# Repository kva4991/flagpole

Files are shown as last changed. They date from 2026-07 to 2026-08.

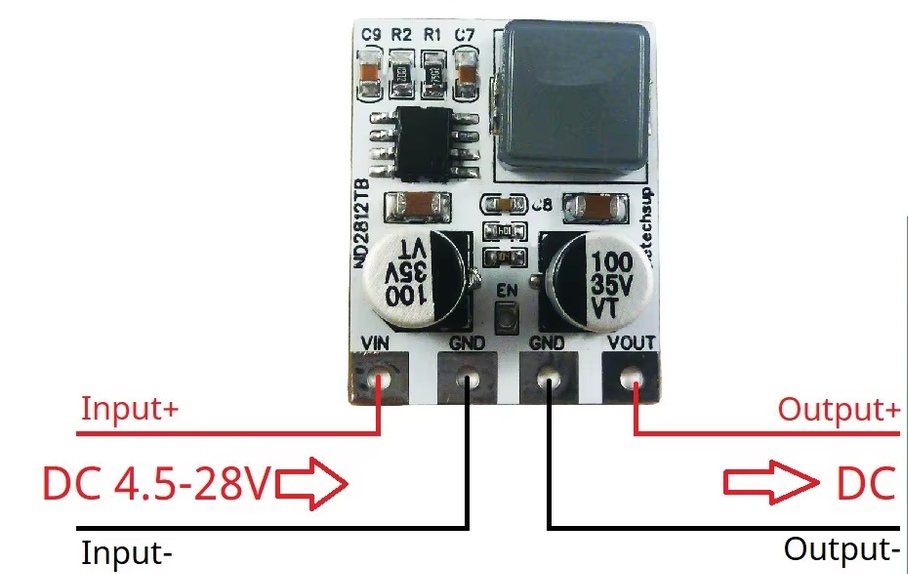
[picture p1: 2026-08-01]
catalog/images/eletechsup_buck_5v_wiring_1005005870795744.png

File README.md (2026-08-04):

# Super_pommels_and_flag rotating flagpole finial v0.7.6

Super_pommels_and_flag is an experimental rotating flagpole-finial project combining printable PETG/TPU mechanics, a 12 V illuminated fish flag, ESP32-C3 firmware, BLE control, a local Android application, and an offline component, drawing, and 3D catalog.

The current cumulative engineering handoff is **v0.7.6**. All 23 canonical printable parts are generated as native build123d/OCP B-Reps rather than copied from transitional meshes. This revision adds captive M4/M3 nuts to every current screw joint, uses a closed twin-bore flag-power guide angled about 35° downward on the lower rounding of `#petg-2`, shortens the VEML7700 light tunnel to 15 mm with a dedicated glue land, adapts the AHT20+BMP280 pocket to a 20 mm adhesive membrane with a 10 mm active centre and seven ventilation holes, and adds a removable two-level electronics carrier.

Rigid parts target the already purchased orange PETG. TPU 95A is used for retained functional soft parts and TPU 85A for static seals. ASA remains a possible future reprint. This is not a production-ready or safety-certified product: purchased-part fits, outdoor durability, sealing, thermal behaviour, wiring, BLE, and structural strength still require physical validation.

## Start here

- [Russian project overview](README.ru.md)
- [Fast start for a new development session](docs/agent-fast-start.ru.md)
- [Current implementation status](docs/current-implementation-status.ru.md)
- [v0.7.6 cumulative update report](UPDATE_REPORT_V076_RU.md)
- [v0.7.6 drawing audit](docs/DRAWING_AUDIT_V074_RU.md)
- [Project identity settings](docs/PROJECT_IDENTITY_RU.md)
- [Required physical measurements](MEASUREMENTS_REQUIRED_RU.md)
- [Architecture decisions](docs/architecture/decisions/README.ru.md)
- [Licensing map](LICENSE.md)
- [Local component, drawing, and 3D catalog](catalog/catalog.html)

## Repository areas

- `mechanical/` — current parametric model generator, 40 validated STL files, seven current GLB files, drawings, previews, and validation data;
- `electronics/` — current wiring drawings and ESP32-C3 firmware;
- `android/` — local BLE control application prototype;
- `catalog/` — generated offline catalog whose sources include `components.json`, the single physical-measurement registry `physical-components.json`, and `drawings.json`;
- `docs/` — current status, design rationale, audits, and immutable ADR history;
- `scripts/`, `tools/quality/`, and `tests/` — reproducibility and repository checks.

Stable filenames containing `v0_6` are retained for compatibility, but their current generated content is version 0.7.6.

The canonical printable source is `mechanical/generate_build123d_canonical_v076.py` and the native STEP/report output is stored in `mechanical/build123d_v076/`. Legacy reference drawings and non-print interactive scenes keep their existing generators and are regenerated only when the owner explicitly requests them.

## Local component, drawing, and 3D catalog

Run from the repository root on Windows:

```powershell
powershell -ExecutionPolicy Bypass -File .\tools\windows\open-component-catalog.ps1
```

The script binds a local server to `127.0.0.1`, opens `catalog/catalog.html`, and enables interactive GLB viewing. Stop it with `Ctrl+C`.

To open the catalog explicitly in Firefox:

```powershell
powershell -ExecutionPolicy Bypass -File .\tools\windows\open-component-catalog.ps1 -Browser Firefox
```

## Regeneration and checks

Run the complete model, drawing, catalog and validation pipeline from the synchronized antivirus-safe worktree:

```powershell
.\build.cmd all
```

The `generate`, `validate`, and `catalog` modes are also available. Large `*.stl` and `*.glb` files use Git LFS; PNG remains in regular Git. GitHub Actions downloads LFS only for the conditional mechanical job.

The checks validate repository consistency and STL topology. They do not establish a verified IP rating, safe load, fit, temperature, lifetime, or correct operation on real hardware.

## License

Project-authored hardware design source, including CAD, drawings and generated
STL/GLB, is licensed under `CERN-OHL-S-2.0`. Project-authored Android, firmware
and repository tooling use the MIT License. Third-party material keeps its own
terms and is not relicensed. See the complete [licensing map](LICENSE.md).

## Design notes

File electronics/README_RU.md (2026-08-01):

# Электроника светящегося флага

## Принятая схема

В этой версии проекта используется минимальная схема без высоковольтного EL-инвертора и без адресных светодиодов:

- в полое древко подаются только `+12 В` и `GND`;
- питание проходит через капсульный токосъёмник;
- одноцветный круглый неон XUNATA 12 В включается низкобоковым MOSFET-модулем;
- ESP32-C3 измеряет освещённость через VEML7700;
- ESP просыпается каждые две минуты, принимает решение и снова уходит в Deep-sleep;
- состояние управляющего GPIO удерживается во время Deep-sleep;
- глаз рыбы является сквозным отверстием, отдельного светодиода в глазу нет.

## Основные компоненты

1. `ESP32-C3 SuperMini Plus V2.0`.
2. `VEML7700` на готовой I²C-плате.
3. DC-DC 12 → 5 В с фиксированным выходом 5 В и заявленными OCP/SCP/OTP.
4. Готовый модуль `PC817 + LR7843`, совместимый с управлением 3,3 В.
5. Круглый одноцветный неон XUNATA 12 В, диаметр 16 мм.
6. Токосъёмник `M125-0205` — предпочтительный двухканальный вариант по 5 А.
7. Герметичный разъём `M12 A-coded, 3 pin, IP67`.
8. Блок питания 12 В, ориентировочно 2 А, у основания флагштока.
9. Плавкий медленный предохранитель — предварительно T1.6A; окончательно выбрать после измерения рабочего тока.
10. `C1` — 1000–2200 мкФ, 25 В возле входа питания вращающейся части.
11. `C2` — 470 мкФ, 16 В возле входа 5 В платы ESP.

TVS, PPTC и последовательный диод от переполюсовки в минимальную первую сборку не включены. При необходимости под них можно оставить монтажные места, но сначала нужно провести стендовые испытания.

## Распиновка ESP32-C3

| Назначение | Контакт |
|---|---:|
| Управление MOSFET-модулем | GPIO3 |
| SDA VEML7700 | GPIO4 |
| SCL VEML7700 | GPIO5 |
| Питание платы ESP | 5V/VBUS от DC-DC |
| Питание VEML7700 | 3V3 от ESP |
| Общий провод | GND |

GPIO2, GPIO8 и GPIO9 в этой версии не используются, поскольку они могут участвовать в загрузочной конфигурации ESP32-C3 либо быть заняты элементами конкретной платы.

## Распиновка M12

Для трёхконтактного M12 A-coded обычно используются контакты 1, 3 и 4:

| Контакт | Назначение |
|---|---|
| Pin 1 | +12 В на светящуюся ленту |
| Pin 3 | коммутируемый минус от MOSFET-модуля |
| Pin 4 | резерв, изолировать |

На навершии желательно установить панельную часть с утопленными контактами. На флаге — кабельную ответную часть.

## Важное замечание по MOSFET-модулю

Китайские платы `PC817 + LR7843` выпускаются с разной маркировкой клемм. Схема в проекте показывает функциональное подключение:

- управляющий вход `IN/SIG` получает GPIO3;
- управляющий `GND/IN-` соединяется с GND ESP;
- силовой GND модуля идёт отдельным проводом к точке `GND STAR`;
- выход модуля коммутирует минус светящейся ленты;
- плюс ленты подключается непосредственно к +12 В.

До окончательной пайки нужно прислать фотографию обеих сторон конкретного модуля: после этого можно подписать каждую клемму без предположений.

## Порядок первого включения

1. Не подключать ESP.
2. Подать 12 В на вход DC-DC.
3. Измерить выход: требуется 4,9–5,1 В.
4. Подключить резистивную или USB-нагрузку около 0,3–0,5 А и проверить напряжение и нагрев.
5. Отдельно проверить светящуюся ленту напрямую от 12 В и измерить рабочий ток после 20 минут работы.
6. Проверить MOSFET-модуль малой нагрузкой.
7. Подключить ESP и VEML7700 без ленты, загрузить прошивку в непрерывном тестовом режиме.
8. Проверить показания датчика при свете и в темноте.
9. Подключить ленту и выполнить не менее 100 циклов включения/выключения.
10. Только после этого включать Deep-sleep и собирать герметичный корпус.

## Калибровка датчика

Начальные пороги в прошивке:

- включение: ниже 8 лк;
- выключение: выше 25 лк;
- включение после 3 подтверждений, то есть примерно через 6 минут;
- выключение после 5 подтверждений, то есть примерно через 10 минут.

Зенитный тоннель уменьшает количество света на датчике. Поэтому пороги нужно откалибровать на полностью собранном колпаке, а не на открытом модуле VEML7700.

## Прошивка

В каталоге `firmware` находятся два варианта:

- `esp32_c3_flag_light` — проект PlatformIO;
- `arduino_ide/esp32_c3_flag_light.ino` — один файл для Arduino IDE.

Основные настройки находятся в `include/config.h` либо в начале `.ino`.

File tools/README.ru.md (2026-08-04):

# Подготовка Windows для Super_pommels_and_flag

<!-- §toolwin -->

В репозитории закреплён воспроизводимый набор инструментов для документации,
Android и двух проектов ESP32-C3. Версии и компоненты объявлены в
`tools/toolchain.json`, установка выполняется сценариями из `tools/windows/`.

> **Обязательное правило:** не запускать Python и команды npm/Node, которые
> косвенно вызывают Python, из исходного Git-worktree даже один раз «для
> проверки». Сначала синхронизировать актуальное дерево в
> `%USERPROFILE%\Documents\pesochnica\flagpole\worktree`, затем выполнять их
> только оттуда. `spawnSync py EPERM` вне защищённой зоны означает ограничение
> места исполнения; повторять запуск в исходной папке не нужно.

Только проверить компьютер:

```powershell
powershell -ExecutionPolicy Bypass -File tools\windows\check.ps1
```

Установить отсутствующие компоненты, принять Android SDK licenses, прогреть
Gradle Wrapper и собрать обе прошивки:

```powershell
powershell -ExecutionPolicy Bypass -File tools\windows\setup.ps1 -Install -AcceptAndroidLicenses
```

Сценарий устанавливает Git/Git Bash, Python, Node.js, JDK 17, GitHub CLI,
7-Zip, ripgrep, Android SDK 35 и PlatformIO Core. PlatformIO устанавливается
официальным installer script в изолированную исполняемую зону
`%USERPROFILE%\Documents\pesochnica\flagpole\.platformio`; глобальный Python не
загрязняется пакетами. Зависимости генерации механики из
`mechanical/requirements.txt` устанавливаются в отдельную среду
`flagpole\.mechanical-venv`; в неё входит переносимый SVG-рендерер `resvg-py`,
поэтому системный Cairo не нужен. Туда же направлен Gradle-кэш, а результаты ручного
экспорта следует класть в `artifacts`. Антивирусное исключение должно
охватывать только папку `flagpole`, не весь каталог `Documents` или исходный
Git-репозиторий.

Скрипт сохраняет пользовательские переменные `FLAGPOLE_EXECUTION_ROOT`,
`PLATFORMIO_CORE_DIR` и `GRADLE_USER_HOME`. Другую папку внутри `pesochnica`
можно передать параметром `-ExecutionRoot`; путь за пределами этой зоны
отвергается.

Перед любой сборкой или проверкой с Python исходники синхронизируются без `.git`
и локальных кэшей в `flagpole\worktree`. Сборка и Python-проверки выполняются
только из этой одноразовой копии. Чистые Node-проверки, заведомо не запускающие
Python, можно выполнять в исходном Git-worktree.
Готовые файлы появляются в `flagpole\artifacts`:

- `crucian-control-debug.apk`;
- `crucian-v06-firmware.bin`;
- `flag-light-legacy-firmware.bin`.

После первого запуска следует открыть новый PowerShell или новый чат Codex,
чтобы процесс получил обновлённые `PATH`, `JAVA_HOME`, `ANDROID_HOME` и
`ANDROID_SDK_ROOT`.

## Единая сборка

После синхронизации исходников в `flagpole\worktree` регенерация канонических
build123d-деталей, постера #204, каталога и проверок выполняется одной командой:

```powershell
.\build.cmd all
```

Режимы `generate`, `validate` и `catalog` позволяют выполнить только нужный
слой. Старые справочные схемы и непечатные сцены в эти режимы не входят. Их
отдельный режим `legacy-references` запускается только по прямому запросу
владельца. `tools/windows/build.ps1` намеренно отказывается запускать
генераторы вне `%USERPROFILE%\Documents\pesochnica\flagpole`, использует
`.mechanical-venv` и `.venv-build123d`, задаёт UTF-8. §build01

Git for Windows должен предоставлять `git lfs`. STL и GLB хранятся через LFS, PNG остаются в обычном Git. CI выполняет `git lfs pull` только в одной условной механической задаче; Android и PlatformIO не скачивают модели.

## Точный CAD: build123d/OCP, FreeCAD и OpenSCAD

FreeCAD и OpenSCAD устанавливаются штатно в стандартные папки Windows через
winget. build123d и OCP являются Python-пакетами, поэтому устанавливаются не как
Windows-программы, а в отдельную среду
`%USERPROFILE%\Documents\pesochnica\flagpole\.venv-build123d`:

```powershell
powershell -ExecutionPolicy Bypass -File tools\windows\setup-cad.ps1 -Install
```

Сценарий повторяет фактически проверенную установку:

```powershell
winget install --id FreeCAD.FreeCAD --exact --source winget
winget install --id OpenSCAD.OpenSCAD --exact --source winget
py -3.12 -m venv "$env:USERPROFILE\Documents\pesochnica\flagpole\.venv-build123d"
& "$env:USERPROFILE\Documents\pesochnica\flagpole\.venv-build123d\Scripts\python.exe" -m pip install build123d==0.11.1 cadquery-ocp-novtk==7.9.3.1.1 trimesh==5.0.0
```

На проверенном компьютере установлены FreeCAD 1.1.3, OpenSCAD 2021.01,
build123d 0.11.1 и OCP 7.9.3.1.1. Повторный запуск без `-Install` только
проверяет наличие программ и импорт модулей. Общий `setup.ps1 -Install` теперь
также вызывает этот CAD-установщик. §cadworkflow

Android собирается закреплённым Wrapper:

```powershell
android\crucian-control\gradlew.bat -p android\crucian-control :app:assembleDebug
```

Прошивка Crucian v0.6:

```powershell
pio run --project-dir electronics\firmware\esp32_c3_crucian_v06
```

Историческая прошивка подсветки:

```powershell
pio run --project-dir electronics\firmware\esp32_c3_flag_light
```

Генерация и проверка актуальной механики из защищённой зоны:

```powershell
& "$env:FLAGPOLE_EXECUTION_ROOT\.venv-build123d\Scripts\python.exe" mechanical\generate_build123d_canonical_v076.py
& "$env:FLAGPOLE_EXECUTION_ROOT\.mechanical-venv\Scripts\python.exe" mechanical\generate_reference_diagrams_v06.py
& "$env:FLAGPOLE_EXECUTION_ROOT\.mechanical-venv\Scripts\python.exe" mechanical\generate_detail_diagrams_v075.py
& "$env:FLAGPOLE_EXECUTION_ROOT\.mechanical-venv\Scripts\python.exe" mechanical\generate_hermeticity_diagram_v075.py
& "$env:FLAGPOLE_EXECUTION_ROOT\.mechanical-venv\Scripts\python.exe" electronics\generate_electronics_diagrams_v075.py
& "$env:FLAGPOLE_EXECUTION_ROOT\.mechanical-venv\Scripts\python.exe" mechanical\validate_models_v06.py
```

`mechanical/generate_models_v06.py` не является генератором актуальных печатных
STL. Он оставлен только для непечатных справочных сцен `#205`, `#209`, `#210` и
не запускается в обычной регенерации печатного комплекта.

Установка инструментов и успешная компиляция не заменяют тесты на ESP32-C3,
телефоне, датчике VEML7700 и силовой нагрузке. §status1

## GitHub Actions

`.github/workflows/validate.yml` повторяет проверки независимо от Windows:

- запускает `npm run quality:core` без скачивания LFS;
- при изменениях механики один раз загружает STL/GLB и запускает `npm run build:ci`;
- собирает Android debug APK через Wrapper;
- собирает оба проекта PlatformIO в матрице;
- публикует APK и два `firmware.bin` как workflow artifacts.

Это основной резервный путь, если локальный антивирус или сетевой фильтр
блокирует загрузку крупного ESP32 toolchain. Зелёная компиляция в GitHub также
не заменяет аппаратный стенд.

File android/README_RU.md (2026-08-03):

# Android-приложение управления

## Изменяемое название

Видимое имя программы и искомое BLE-имя задаются в корневом файле:

```text
project_identity.json
```

После изменения выполнить:

```powershell
npm.cmd run identity:generate
```

Технический package — `ru.superpommelsandflag.crucian`: только нижний регистр и без подчёркиваний, чтобы Android application ID оставался корректным.

## Реализованные функции

- поиск BLE-устройства по generated-имени;
- явная машина состояний;
- MTU negotiation;
- системный bonding/PIN;
- последовательная очередь GATT-операций;
- подписка на статус;
- AUTO/ON/OFF;
- ручная яркость;
- калибровка дня и ночи;
- смена PIN;
- команда отключения BLE;
- отображение света, температуры, влажности и давления;
- корректное закрытие GATT и остановка сканирования.

Напряжение аккумулятора намеренно не отображается: в проекте нет аппаратного измерителя этой величины.

## Машина состояний

```text
IDLE
 → SCANNING
 → CONNECTING
 → NEGOTIATING_MTU
 → BONDING
 → DISCOVERING_SERVICES
 → SUBSCRIBING
 → READING_CONFIGURATION
 → READY
```

Ошибки переводят клиента в `ERROR`. Ручное отключение использует `DISCONNECTING`.

## Очередь GATT

В каждый момент выполняется только одна операция. Следующая запускается после callback предыдущей или после ошибки/тайм-аута.

## Что проверить на телефоне

- разрешения Android 8–15;
- системный PIN-диалог;
- неверный PIN;
- смену PIN и удаление старого bond;
- повторное подключение;
- потерю связи во время каждой фазы;
- несколько последовательных команд;
- уход приложения с экрана и уничтожение ViewModel.

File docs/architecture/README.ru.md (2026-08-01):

# Архитектура Crucian

Архитектура разделяет физическую силовую цепь, электронику управления, программное состояние и документационные доказательства.

## Подсистемы

1. Механика: неподвижный узел на древке, два подшипника, вращающийся корпус и боковая спица.
2. Питание: аккумуляторный источник, стабилизированная шина 12 В, DC-DC 5 В и защита.
3. Нагрузка: одноцветный неон 12 В, коммутируемый MOSFET с PWM от ESP32-C3.
4. Управление: VEML7700 для автоматики света, комбинированный AHT20+BMP280 для климата, локальная BLE-сессия и Android-клиент.
5. Обслуживание: съёмные детали, дренаж, тестовые купоны, измерения и стендовые проверки.

Принятые решения и история их замены находятся в [индексе ADR](decisions/README.ru.md). Текущий, ещё не обязательно подтверждённый код описывается отдельно в [статусе реализации](../current-implementation-status.ru.md).

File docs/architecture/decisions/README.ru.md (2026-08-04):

# Архитектурные решения

Принятые решения не переписываются задним числом. Изменение оформляется новым последовательным ADR. §adrproc

| ADR | Статус | Решение |
| --- | --- | --- |
| [0001](0001-power-and-load-path.ru.md) | Принято | Внешняя 6×18650-подсистема предоставляет стабилизированные 12 В |
| [0002](0002-ble-service-window.ru.md) | Принято | BLE-окно один час после настоящего включения питания |
| [0003](0003-structural-material-boundaries.ru.md) | Принято | Два подшипника, боковая спица и границы TPU |
| [0004](0004-documentation-process.ru.md) | Принято | Управляемая документация и quality gate |
| [0005](0005-asa-preferred-outdoor-material.ru.md) | Принято | ASA как возможный наружный материал |
| [0006](0006-environment-sensors.ru.md) | Заменено 0007 | Переход от NTC к цифровым датчикам |
| [0007](0007-combined-aht20-bmp280.ru.md) | Принято | Комбинированный AHT20+BMP280 |
| [0008](0008-environment-sensor-pocket.ru.md) | Принято | Нижний защищённый карман датчика |
| [0009](0009-electronics-vent-membrane.ru.md) | Заменено 0023 | Предварительный малый формат vent-мембраны |
| [0010](0010-cut-light-well-window.ru.md) | Принято | Вырезаемое прозрачное окно VEML7700 |
| [0011](0011-flag-sewing-thread.ru.md) | Принято | УФ-стойкая полиэстеровая нить |
| [0012](0012-petg-now-asa-later.ru.md) | Принято | PETG сейчас, ASA позднее после купонов |
| [0013](0013-project-identity-source.ru.md) | Принято | Единый источник имени проекта и BLE |
| [0014](0014-captive-nut-pockets.ru.md) | Принято | Параметрические закладные карманы |
| [0015](0015-flag-attachment-loops.ru.md) | Принято | Четыре тканевые лямки |
| [0016](0016-android-ble-state-machine.ru.md) | Принято | Android BLE state machine и очередь GATT |
| [0017](0017-external-flag-power-cable-route.ru.md) | Заменено 0022 | Базовый наружный маршрут питания |
| [0018](0018-multibarrier-weatherproofing.ru.md) | Принято | Независимые обслуживаемые барьеры |
| [0019](0019-flag-loop-placement.ru.md) | Заменено 0021 | Старое положение лямок относительно полотна |
| [0020](0020-drawing-status-and-canonical-meshes.ru.md) | Заменено 0025 | Переходные канонические сетки v0.7.3 |
| [0021](0021-flag-loop-datum-below-finial.ru.md) | Принято | Верхняя лямка на 10 мм ниже низа навершия |
| [0022](0022-angled-flag-wire-guide.ru.md) | Принято | `#tpu95-10` под 35° в отмеченной точке |
| [0023](0023-adhesive-membrane-20mm-seven-holes.ru.md) | Принято | Мембрана Ø20 и семь отверстий Ø2 |
| [0024](0024-removable-electronics-carrier.ru.md) | Принято | Съёмный двухуровневый каркас электроники |
| [0025](0025-fully-parametric-current-mechanics.ru.md) | Принято | Полностью параметрическая current-механика |
| [0026](0026-current-only-catalog-and-part-id-callouts.ru.md) | Принято | Только актуальные карточки и обязательные ID-выноски вне раскладок печати |
- [ADR-0027: чистые миниатюры и управляемые ID-метки](0027-clean-thumbnails-and-controllable-id-callouts.ru.md)
- [ADR-0028: компактные одно-материальные раскладки](0028-compact-single-material-print-layouts.ru.md)
- [ADR-0029: build123d-mcp как вспомогательный CAD-контур](0029-build123d-mcp-pilot.ru.md)
- [ADR-0030: Git LFS и единый сборочный интерфейс](0030-git-lfs-and-unified-build.ru.md)
- [ADR-0031: раздельные лицензии аппаратуры и ПО](0031-split-hardware-and-software-licensing.ru.md)
- [ADR-0032: один медиа-ID — один подробный rationale-файл](0032-one-media-id-one-rationale-file.ru.md)
- [ADR-0033: компактный критический контракт в каждом медиа-описании](0033-compact-critical-contract-per-media.ru.md)
- [ADR-0034: единый реестр физических размеров компонентов](0034-single-physical-component-measurement-registry.ru.md)
- [ADR-0035: жёсткая PETG-втулка 6806 и независимые посадочные пробники](0035-rigid-petg-6806-adapter-and-independent-fit-coupons.ru.md)
- [ADR-0036: закрытая гибкая разгрузка кабеля в нижнем торце секции](0036-lower-pole-flexible-cable-strain-relief.ru.md)
- [ADR-0037: не хранить устаревшие бинарные генерации в текущем дереве](0037-prune-superseded-generated-binaries.ru.md)

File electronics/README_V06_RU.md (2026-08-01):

# Электроника и прошивка v0.7

## Питание

Внешний аккумуляторный узел 6×18650 подаёт стабилизированные 12 В. Проект навершия не проектирует BMS и зарядку.

Измерение напряжения аккумулятора не реализуется: нет делителя ADC, поля `BAT` и соответствующего показания Android.

## Имена проекта

Прошивка получает BLE-имя и публичное имя из generated-файла, создаваемого из `project_identity.json`.

## Датчики

- VEML7700 — освещённость и fail-safe;
- AHT20 — температура/влажность;
- BMP280 — давление и резервная температура.

Все датчики используют I²C GPIO4/GPIO5 и питание 3,3 В.

## Подсветка

```text
12 В → XUNATA Ø16 мм → LR7843 → GND
GPIO3 PWM → затвор LR7843
```

Если используется плата PC817+LR7843, допускается подпайка PWM непосредственно к затвору после проверки схемы и общего GND.

## BLE

- окно 1 час после настоящей подачи питания;
- Deep-sleep не открывает окно снова;
- после bonding BLE остаётся активным до power cycle или `BLE:OFF`;
- PIN не читается через GATT;
- смена PIN удаляет bonds.

## Проверки стенда

1. Фактическая полярность и уровень затвора LR7843.
2. Нагрев ключа при полном токе ленты.
3. Ошибка VEML7700 и выключение света после трёх ошибок.
4. Адреса AHT20/BMP280.
5. BLE cold boot → час → lock → Deep-sleep → power cycle.

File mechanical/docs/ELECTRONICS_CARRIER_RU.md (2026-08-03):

# Съёмный каркас электроники v0.7.6

## Компоновка

`#petg-9` является единой съёмной деталью внутри бокса:

- DC-DC 12→5 В лежит горизонтально на нижнем уровне;
- ESP32-C3 стоит вертикально на стенке `+Y`, антенной в сторону флага и от силовых узлов;
- MOSFET стоит вертикально на противоположной стенке `−Y`;
- силовые провода прокладываются вдоль `−Y`, I²C — вдоль `+Y`;
- прорези допускают регулируемые TPU-стяжки;
- ввод проводов флага разгружается до клемм;
- USB-C, кнопки ESP32 и клеммы доступны после снятия крышки.

Отдельная опора `#petg-10` держит VEML7700 над каркасом и крепится двумя M3-закладными.

## Ограничения

Все объёмы плат пока условные. До печати полного каркаса измерить длину, ширину, толщину, максимальную высоту компонентов, положение USB-C, кнопок, клемм, отверстий и направление выхода проводов. После сборки проверить нагрев DC-DC и MOSFET при максимальной яркости неона.

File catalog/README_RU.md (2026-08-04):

# Каталог компонентов и локальная HTML-страница

<!-- §catalog -->

## Источники

- `catalog/components.json` — карточки компонентов и материалов;
- `catalog/physical-components.json` — единственный редактируемый источник физических размеров, массы, статуса измерения и потребности в дополнительных замерах для каждого component-ID; §physicalcomponents1
- `catalog/drawings.json` — только актуальные чертежи, модели и очереди печати; он хранит структуру карточек и ссылки `descriptionFile`, но не подробные пояснения;
- `mechanical/cad_drafts/*.json`, перечисленные в `catalogPolicy.cadDraftSources`, — единые размерные источники ещё не сгенерированных CAD-заготовок; сайт показывает их без выдуманного PNG/STL/GLB;
- `catalog/media-descriptions/<ID>.md` — единственный подробный текст по конкретному медиа-ID: что показано, почему принято такое изображение/геометрия, какие допущения действуют и что обновлять одновременно; §mediarationale1
- `mechanical/part_id_registry_v06.json` — канонические ID печатных деталей;
- `VERSION.txt` — единственная версия, допустимая в рабочем каталоге;
- `scripts/generateComponentCatalog.mjs` — генератор `catalog/catalog.html`;
- `mechanical/render_catalog_part_callouts_v075.py` — генератор подписанных PNG-копий.

`catalog/catalog.html` — производный файл. Вручную его не редактировать.

## Политика current-only

Медиа-массивы рабочей вкладки «Чертежи и 3D» показывают только `status: "current"`. Любая медиа-запись с `historical`/`reference` либо версией, отличной от `VERSION.txt`, останавливает генерацию с ошибкой. Единственное немедийное исключение — отдельный блок исходных CAD-заготовок со статусом `source-only-not-generated`: у него по определению нет производного файла. Исторические файлы могут лежать в репозитории, но не должны присутствовать в массивах рабочего каталога.

Отдельной вкладки «Новый CAD» нет. Экспериментальные модели не публикуются в рабочем каталоге. Исходная заготовка без производных файлов может отображаться только в существующей вкладке «Чертежи и 3D», если её JSON перечислен в `catalogPolicy.cadDraftSources`, имеет статус `source-only-not-generated`, содержит размеры, зависимости и ссылку на воспроизводимый источник. Такой блок нельзя выдавать за готовую к печати модель.

Поэтому карточки наподобие «Общий вид сборки v0.5 — интерактивно» или «Раскладка TPU v0.5 — историческая» не скрываются CSS и не фильтруются после загрузки: их вообще нет в источнике рабочего HTML.

## ID-выноски

Каждый непечатный чертёж обязан использовать `calloutMode: "overlay"` или `embedded`. Каждая непечатная модель обязана использовать `calloutMode: "hotspots"`. Допустимы только существующие ID компонентов и печатных деталей.

Раскладки печати — единственное исключение. Они получают `kind: "print-layout"`, `calloutMode: "exempt"` и объяснение причины. Подписи на них запрещены, чтобы не закрывать ориентацию, контуры и зазоры.

Подробная схема полей и порядок выпуска описаны в `docs/CATALOG_MEDIA_POLICY_RU.md`, ADR-0026 и ADR-0032.

## Подробные описания по ID

Каждая запись из массивов `drawings`, `models` и `printSessions` имеет ровно один файл `catalog/media-descriptions/<ID>.md`. Имя файла, `id` во front matter и ID карточки должны совпадать. Перед изменением чертежа, модели, ракурса, выноски, посадки, упрощённого референса или смысла карточки агент обязан прочитать этот файл полностью. После изменения его обновляют в той же правке вместе с первичным CAD/SVG-источником и производными файлами.

Подробное объяснение не дублируется в `drawings.json`: поле `description` запрещено. Тематические документы в `mechanical/docs/` сохраняются, потому что описывают подсистему сразу для нескольких медиа; ID-файл даёт именно контекст конкретного изображения или модели и ссылается на эти документы. Краткая аннотация карточки берётся из `summary` front matter, а полный текст открывается ссылкой «Подробное описание #ID».

Контракт, существование основного файла/источника и отсутствие повторяющегося rationale вне ID-папки проверяются командой:

```powershell
npm.cmd run media:descriptions:check
```

## Почему исходные чертежи остаются чистыми

<!-- v076-clean-thumbnails:start -->
## Чистые миниатюры и полноэкранные ID

Карточки 2D используют поле `thumbnail` и всегда показывают чистый исходный preview. Подписанная `annotatedPreview` открывается только как полный документ. В карточках 3D hotspots скрыты, но при переходе на весь экран копируются в viewer. Кнопка с пиктограммой глаза и надписью `ID` рядом с крестиком позволяет временно скрыть или вернуть их.

`labelPosition` задаёт предпочтительное направление. Фактическую близкую позицию выбирает `render_catalog_part_callouts_v075.py`; итоговые метрики записываются в `mechanical/CALLOUT_LAYOUT_REPORT_V076.json`.
<!-- v076-clean-thumbnails:end -->

Размерный SVG и базовый PNG должны быть пригодны для инженерной проверки и повторного использования. Выноски строятся как отдельные PNG в `catalog/annotated/`; пользователь видит подписанную версию, а рядом получает ссылку «Исходник без выносок». ID рисуются встроенным пиксельным алфавитом и не зависят от установленных в ОС шрифтов.

В GLB подписи реализуются hotspots web-компонента `<model-viewer>`. Текст не превращается в сетку и не попадает в STL/печать. Hotspots копируются в полноэкранный режим.

## Компоненты

ID компонентов состоят из трёх цифр и идут без пропусков. `imageStatus` принимает `confirmed`, `listing`, `reference` или `placeholder`. Справочная фотография не подтверждает конкретную купленную модель; неподтверждённые характеристики явно отмечаются в тексте.

`components.json` хранит назначение, названия, электрические характеристики и ссылки, но не геометрические размеры. Все измеренные, расчётные, стандартные, заявленные продавцом и предварительные физические величины записываются только в `physical-components.json`. Сайт объединяет оба источника по ID и создаёт постоянные адреса `catalog.html#component-001` … `catalog.html#component-025`. Текстовые документы ссылаются на такой адрес вместо копирования числа. Размеры печатных деталей остаются в параметрическом CAD и его отчёте, а не переносятся в реестр покупных компонентов.

Если владелец прислал новый замер, агент обновляет соответствующую запись `measurements`, статус и источник. Поле `needs` сохраняет только ещё отсутствующие данные. Ручное дублирование числа в `components.json`, актуальном README или медиа-описании запрещено; исторические ADR и отчёты могут сохранять значения времени принятия решения, если явно остаются историческими.

## Перегенерация

Из корня проекта:

```powershell
npm.cmd run media:descriptions:check
npm.cmd run catalog:generate
npm.cmd run catalog:check
npm.cmd run models:semantics:check
```

Npm-команды используют `scripts/runPython.mjs`: на Windows поддерживается `py -3`, на Linux/macOS — `python3`, также можно задать `FLAGPOLE_PYTHON`.

Для полного выпуска сначала перегенерируются механика, схемы и превью, затем слой выносок и HTML.

## Локальный просмотр

Вес каждого изображения, постера и GLB выводится непосредственно в карточке. Генератор вычисляет его из текущего файла, а для Git LFS — из поля `size` указателя, поэтому после замены медиа значение обновляется автоматически при `catalog:generate` и не хранится вручную в JSON.

```powershell
py -m http.server 8080 --bind 127.0.0.1
```

Открыть:

```text
http://127.0.0.1:8080/catalog/catalog.html
```

Привязка к `127.0.0.1` обязательна. Для GLB нужен HTTP-сервер; из `file://` браузер может блокировать локальную модель. Интернет используется только для загрузки `<model-viewer>`, сами GLB остаются локальными.

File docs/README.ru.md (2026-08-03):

# Карта документации Crucian

Документация разделена по роли, чтобы новая сессия не перечитывала весь репозиторий и не путала планы с реализованным состоянием. §faststart

## Точки входа

- [Быстрый старт агента](agent-fast-start.ru.md) — минимальный маршрут чтения.
- [Текущий статус](current-implementation-status.ru.md) — что реализовано, проверено или ещё требует стенда.
- [Аудит v0.6.1](AUDIT_V061_RU.md) — найденные риски и границы доказательств.
- [Процесс ведения документации](DOCUMENTATION_WORKFLOW_RU.md) — README, focused docs, ADR, §-теги и quality gate.
- [Архитектура](architecture/README.ru.md) — карта подсистем и принятых решений.
- [Карта §-тегов](dev/tag-map.md) — стабильные связи между правилами, кодом и проверками.

## Текущие документы v0.7.6

- [Сводка проектных решений](PROJECT_DECISIONS_RU.md)
- [Отчёт обновления v0.7.6](../UPDATE_REPORT_V076_RU.md)
- [Политика текущего каталога и подписей](CATALOG_MEDIA_POLICY_RU.md)
- [Обоснование прошивки и Android](CODE_RATIONALE_RU.md)
- [Передача следующему чату](NEXT_CHAT_HANDOFF_RU.md)

## Специализированные разделы

- [Электроника и прошивка v0.6](../electronics/README_V06_RU.md)
- [Android-прототип](../android/README_RU.md)
- [Каталог компонентов](../catalog/README_RU.md)
- [Механическая сборка PETG/TPU v0.7.6](../mechanical/docs/ASSEMBLY_PETG_TPU_RU.md)
- [Печать PETG/TPU v0.7.6; ASA только как будущая замена](../mechanical/docs/PRINTING_PETG_TPU_RU.md)
- [Обязательные измерения](../MEASUREMENTS_REQUIRED_RU.md)

## История

- [Аудит v0.6.1](AUDIT_V061_RU.md) и [история решений v0.6.1](CHANGELOG_DECISIONS_V061_RU.md) сохраняют состояние соответствующего среза;
- отчёты v0.5–v0.7.4 и материалы в `archive/` служат происхождением решений.

Исторические документы не переопределяют ADR и текущий статус v0.7.6.

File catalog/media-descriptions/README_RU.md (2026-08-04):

# Подробные описания чертежей и 3D-моделей

<!-- §mediarationale1 -->

Эта папка является единственным источником подробного текстового объяснения каждого медиаобъекта рабочего каталога.

## Основное правило

Каждой записи `drawings`, `models` или `printSessions` из `catalog/drawings.json` соответствует ровно один файл:

```text
catalog/media-descriptions/<ID>.md
```

Примеры:

- карточка чертежа `101` → `catalog/media-descriptions/101.md`;
- интерактивная модель `205` → `catalog/media-descriptions/205.md`;
- очередь печати `303` → `catalog/media-descriptions/303.md`.

Имя файла, поле `id` в его метаданных и ID карточки обязаны совпадать. На сайте ID отображается с ровно одним символом `#`, но имя файла остаётся цифровым: `101.md`, а не `#101.md`.

Сгенерированная навигационная таблица всех карточек находится в [`INDEX_RU.md`](INDEX_RU.md). Она содержит ID, тип, основной медиафайл, источник истины, размер и сокращённую SHA-256; вручную таблицу не редактировать.

## Зачем введены отдельные файлы

В одном таком файле закрепляются:

- назначение и границы конкретного рисунка или 3D-модели;
- состав показанных элементов;
- причины выбранного ракурса, разреза, разнесения, цвета и уровня детализации;
- смысл каждой выноски и связь с каноническими ID;
- сборочная, эксплуатационная и сервисная логика;
- предварительные размеры и неподтверждённые допущения;
- перечень файлов и документов, которые меняются одновременно;
- обязательные автоматические, визуальные и физические проверки.

Такой текст нельзя сокращать до одной строки в JSON или повторять вручную в сгенерированном HTML: два независимых описания неизбежно расходятся.

## Что остаётся в `catalog/drawings.json`

JSON хранит только структурные данные карточки:

- ID, название, статус, версию и тип;
- путь к медиафайлу и превью;
- режим выносок;
- координаты выносок/hotspots;
- путь `descriptionFile` к единственному Markdown-описанию.

Поле `description` в JSON запрещено. Краткий текст карточки каталога берётся из `summary` соответствующего Markdown-файла.

## Что не считается дублированием

Профильные документы в `mechanical/docs/`, `electronics/` и `docs/` сохраняются. Они описывают общие инженерные требования к узлу, материалу или процессу и могут использоваться несколькими рисунками. Файл этой папки объясняет **конкретное представление**: почему карточка с данным ID показывает именно такой набор элементов, ракурс и уровень детализации.

Допустима ссылка на профильный документ. Недопустимо копировать туда или обратно целый rationale карточки и поддерживать две версии одного объяснения.

Физические размеры и масса покупных компонентов являются отдельной зависимостью: они хранятся только в `catalog/physical-components.json`. Если медиа зависит от реального компонента, описание использует точную ссылку `../catalog.html#component-<ID>` и тег §physicalcomponents1, не копируя число. Размеры собственной печатной геометрии по-прежнему задаются каноническим CAD.

## Обязательная структура файла

Каждый `<ID>.md` содержит блок метаданных, короткий критический контракт и девять подробных разделов:

0. критический контракт: что нельзя потерять, что запрещено и что проверить после генерации;
1. назначение и границы;
2. источник истины и связанные файлы;
3. что показано;
4. почему изображено именно так;
5. разбор элементов и ID;
6. сборочная, эксплуатационная и сервисная логика;
7. предварительные параметры и неподтверждённые допущения;
8. что обновлять одновременно;
9. проверка после изменения.

Критический контракт находится сразу после строки статуса, до длинного rationale. В каждом из трёх подразделов должно быть минимум два конкретных пункта. Он не заменяет подробные разделы: это обязательная краткая памятка, по которой агент проверяет, что мелкие конструктивные и сервисные элементы не исчезли при новой генерации. §mediacontract1

В метаданных обязательны `id`, `catalogSection`, `mediaType`, `version`, `status`, `mediaFile`, `title`, `summary` и `sourceOfTruth`.

## Порядок изменения модели или рисунка

До моделирования или редактирования агент обязан:

1. открыть карточку в `catalog/drawings.json`;
2. прочитать одноимённый файл из этой папки полностью;
3. прочитать перечисленные в нём профильные документы;
4. проверить, не нарушает ли правка закреплённую сборочную или сервисную логику.

После правки агент обязан обновить описание в том же изменении, даже когда ID и название карточки не менялись. Если геометрия изменилась, а `<ID>.md` остался прежним без обоснования, работа не считается завершённой.

## Проверка

```powershell
npm.cmd run media:descriptions:check
npm.cmd run catalog:generate
npm.cmd run catalog:check
npm.cmd test
```

Валидатор проверяет соответствие один-к-одному, имя файла, метаданные, существование `mediaFile` и `sourceOfTruth`, критический контракт с тремя подразделами, обязательные подробные разделы, минимальную подробность, уникальность summary и полного текста, отсутствие поля `description` в JSON, отсутствие файлов-сирот и отсутствие повторов существенного rationale в других редактируемых файлах.

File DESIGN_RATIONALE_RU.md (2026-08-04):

# Подробное обоснование конструкции вращающегося навершия v0.2

> **Историческая справка.** Разделы 1–28 описывают предварительную архитектуру v0.2
> и не являются актуальной инструкцией по изготовлению. Текущие решения v0.7.4
> находятся в `README.md`, `docs/NEXT_CHAT_START_HERE_RU.md`,
> `MEASUREMENTS_REQUIRED_RU.md` и ADR. При противоречии приоритет имеют актуальные
> документы; предварительные посадочные размеры нельзя считать подтверждёнными до измерений.

> **Результат измерения 2026-08-04:** актуальные значения находятся только в карточке [древка #015](catalog/catalog.html#component-015), а выбранный новый кандидат — в карточке [подшипника #008](catalog/catalog.html#component-008). Поэтому описанная ниже прямая схема с 6804-2RS отклонена. Текст о прежних размерах сохранён только как история принятия решений; для изготовления он не применяется. §physicalcomponents1

## 1. Назначение документа

Этот документ объясняет, почему предварительная модель v0.2 устроена именно так, какие нагрузки и способы отказа учитывались, какие решения сознательно не применялись и какие части конструкции пока остаются условными.

Навершие проектируется для небольшого флага приблизительно 300 × 250 мм. Верхняя кромка флага удерживается горизонтальной углепластиковой спицей. Вся печатная часть со спицей и флагом должна поворачиваться вокруг вертикального древка подобно флюгеру. При этом вращение должно оставаться лёгким, а изгибающая нагрузка от длинной спицы не должна закусывать подшипники.

Версия v0.2 является инженерным прототипом. Она уже имеет внутренне непротиворечивую компоновку, но ещё не может считаться окончательной, потому что реальное древко не измерено. Особенно важны фактический наружный диаметр верхнего участка, длина прямого цилиндрического участка, наличие нижнего уступа и точная конструкция верхней резьбы.

## 2. Исходные данные и неопределённости

На текущем этапе известны или предполагаются следующие данные:

- высота флага: около 250 мм;
- ширина флага: около 300 мм;
- верхняя часть древка: предположительно около 20 мм по наружному диаметру;
- на верхнем торце есть резьба, предварительно предполагается M5;
- спица должна быть углепластиковой;
- конструкция должна быть максимально простой;
- вращающаяся часть не должна опираться пластиком непосредственно на древко;
- длинная спица не должна проходить через вертикальную ось;
- допускается два или больше подшипников, если это действительно нужно.

Пока неизвестны:

- точный диаметр и овальность древка;
- является ли резьба наружной или внутренней;
- шаг и длина резьбы;
- высота торца относительно возможного нижнего уступа;
- существует ли штатная опорная ступень под нижнее внутреннее кольцо;
- диаметр и тип углепластиковой спицы;
- жёсткость и плотность ткани;
- точный способ крепления флага;
- материал и точность FDM-печати.

Из-за этих неопределённостей v0.2 разделяет детали на две группы:

1. геометрия, которую уже можно определить принципиально: вращающийся корпус, взаимное положение двух подшипников и спицы, способ разъёма, зажим углепластика;
2. геометрия, которую нельзя честно завершить до измерений: верхний фиксатор M5, нижний неподвижный упор и окончательная посадка внутренних колец на древко.

## 3. Почему версия v0.1 была переработана

В первой концепции использовалась отдельная вертикальная ось M8 и два подшипника 608. Горизонтальный канал спицы находился в верхней части корпуса и геометрически пересекал эту ось. Такое пересечение делало реальную сборку невозможной: сплошная ось и сплошная спица не могут одновременно занимать один и тот же объём.

Кроме того, предположение об «20 мм» было истолковано как внутренний диаметр трубы. Позже выяснилось, что речь, вероятнее всего, идёт о наружном диаметре верхнего участка древка. Это полностью меняет способ крепления.

В v0.2 оба противоречия устранены:

- спица перенесена в промежуток между подшипниками;
- её канал сделан глухим и заканчивается до центральных неподвижных деталей;
- ось вращения формируется непосредственно древком условного диаметра 20 мм и двумя подшипниками 6804;
- печатная вставка внутрь трубы исключена до получения реальных размеров.

## 4. Общая кинематическая схема

В конструкции есть две группы деталей.

### 4.1. Неподвижная группа

Неподвижны относительно древка:

- само древко;
- внутреннее кольцо нижнего подшипника;
- металлическая распорная втулка между внутренними кольцами;
- внутреннее кольцо верхнего подшипника;
- нижний опорный уступ или отдельный неподвижный упор;
- верхний ступенчатый фиксатор;
- винт или гайка на предполагаемой резьбе M5.

### 4.2. Вращающаяся группа

Вместе вращаются:

- наружные кольца обоих подшипников;
- две половины печатного корпуса;
- зажатая углепластиковая спица;
- прикреплённый к ней флаг;
- винты и гайки, соединяющие половины корпуса.

Между этими группами не должно быть прямого скольжения пластика по металлу. Относительное движение происходит только внутри подшипников.

## 5. Почему выбраны два подшипника

Один подшипник способен обеспечить вращение, но плохо сопротивляется опрокидывающему моменту от длинной боковой консоли. Внутри обычного радиального подшипника есть небольшой зазор. Если единственная опора находится в одной плоскости, конец спицы может заметно качаться, а наружное кольцо будет пытаться наклониться относительно внутреннего.

Два разнесённых подшипника образуют опорную базу. Боковой момент превращается в пару противоположных радиальных реакций:

- верхний подшипник воспринимает усилие в одну сторону;
- нижний — в противоположную;
- чем больше расстояние между центрами, тем меньше сила в каждой опоре при том же моменте.

В v0.2 центры подшипников разнесены на 32 мм. Ось спицы находится точно посередине, поэтому расстояние до каждого центра равно 16 мм.

### 5.1. Почему не установлен третий подшипник

Третий подшипник не добавляет принципиально нового типа опоры. Чтобы три радиальных подшипника работали одновременно без внутреннего напряжения, их посадочные оси должны быть практически идеально соосны. В точёном металлическом корпусе это достижимо. В двух половинах, изготовленных FDM-печатью, возможны:

- усадка;
- небольшое коробление;
- «слоновья нога»;
- неодинаковая затяжка винтов;
- локальная овальность посадок;
- смещение половин относительно друг друга.

При трёх опорах одна из них почти неизбежно начнёт поджимать вал или внутреннее кольцо, повышая трение. Поэтому для простой печатной конструкции правильная последовательность улучшений такова:

1. два подшипника;
2. максимально возможное разумное расстояние между ними;
3. точные тестовые посадки;
4. жёсткий корпус;
5. только после испытаний — рассмотрение другой архитектуры.

Количество подшипников не следует увеличивать просто «для запаса». В данном случае это может уменьшить надёжность.

## 6. Почему предварительно выбраны 6804-2RS

Подшипник 6804 имеет базовые размеры 20 × 32 × 7 мм. Его внутренний диаметр совпадает с предполагаемым наружным диаметром верхнего участка древка.

Преимущества такой схемы:

- не требуется длинная отдельная ось малого диаметра;
- изгиб передаётся через сравнительно массивное древко Ø20 мм;
- подшипники располагаются близко к несущей детали;
- уменьшается число переходных деталей;
- верхняя резьба M5 не становится основной изгибаемой осью;
- корпус получается компактнее, чем при установке крупной внешней втулки вокруг отдельной оси.

Однако это решение применимо только при подходящем реальном диаметре древка. Подшипниковая посадка имеет значительно более строгие требования, чем декоративная труба или окрашенное древко. Возможны следующие проблемы:

- фактический диаметр больше 20 мм, и подшипник не надевается;
- краска создаёт наплывы;
- диаметр меньше 20 мм, и внутреннее кольцо болтается;
- древко овальное;
- прямой участок слишком короткий;
- есть сварной шов или конус.

Поэтому подшипники 6804 не следует покупать большой партией и тем более забивать на древко до измерений. В архив включён тест посадочного места корпуса, но он проверяет только наружное кольцо. Применимость внутреннего диаметра проверяется непосредственно на реальном древке.

## 7. Роль верхней резьбы M5

Предполагаемая M5 не используется как единственная длинная ось вращения. Она выполняет более простую и подходящую для неё задачу: создаёт осевое прижимное усилие для неподвижного пакета внутренних колец.

Правильный путь силы при затяжке:

1. винт или гайка M5 давит на верхний ступенчатый фиксатор;
2. фиксатор касается внутреннего кольца верхнего подшипника;
3. верхнее внутреннее кольцо давит на металлическую распорную втулку;
4. втулка давит на внутреннее кольцо нижнего подшипника;
5. нижнее внутреннее кольцо опирается на неподвижный уступ или отдельный упор.

Шарики и наружные кольца не должны быть частью этого пути затяжки.

### 7.1. Почему нельзя прижать весь подшипник обычной широкой шайбой

Если верхняя шайба одновременно касается внутреннего и наружного кольца, вращение будет заторможено. Если шайба давит на вращающийся печатный корпус, корпус также окажется зажат между неподвижными деталями.

Поэтому верхний фиксатор должен быть ступенчатым:

- нижняя узкая часть входит в центральное отверстие печатной крыши;
- её диаметр выбирается так, чтобы она касалась только внутреннего кольца;
- между ней и вращающимся корпусом остаётся радиальный зазор;
- верхняя часть образует козырёк и место под винт или гайку.

Точная форма не завершена, потому что неизвестно, где находится торец древка и какая именно резьба установлена.

### 7.2. Почему нужна нижняя опора

Одного верхнего винта недостаточно. Чтобы стянуть пакет, усилию нужен нижний реактивный упор. Им может быть:

- штатный уступ на древке;
- металлическое разрезное установочное кольцо;
- отдельная неподвижная втулка;
- специальный адаптер, охватывающий верх древка.

Если прямое древко не имеет уступа, нижний упор придётся спроектировать отдельно. Печатное кольцо, удерживаемое только трением, нежелательно для постоянной нагрузки: пластик способен ползти, особенно при нагреве.

## 8. Металлическая распорная втулка

Между внутренними кольцами предусмотрена металлическая трубчатая втулка:

- наружный диаметр около 24 мм;
- внутренний диаметр около 20,3 мм;
- длина 25 мм.

Длина получается из геометрии:

- расстояние между центрами подшипников: 32 мм;
- ширина каждого подшипника: 7 мм;
- свободный промежуток между внутренними торцами: 32 − 7 = 25 мм.

Втулка выполняет три функции:

1. передаёт осевое усилие затяжки от верхнего внутреннего кольца к нижнему;
2. сохраняет расстояние между внутренними кольцами;
3. предотвращает создание нежелательного осевого преднатяга через шарики.

Внутренний диаметр 20,3 мм выбран предварительно, чтобы втулка могла надеться на условное древко 20 мм. Реальная величина зависит от измерений.

Пластиковую втулку можно использовать только для первого примерочного прототипа. Для постоянной сборки предпочтительна металлическая: алюминиевая, латунная или стальная, с ровными параллельными торцами.

## 9. Как предотвращается закусывание подшипников

Закусывание чаще вызывается не самой нагрузкой флага, а неправильной посадкой и затяжкой.

В v0.2 применены несколько независимых мер.

### 9.1. Наружные кольца не запрессовываются силой

Корпус разъёмный. Подшипники укладываются в открытые полуокружности, после чего половины соединяются. Это лучше, чем забивать подшипник в цельное печатное отверстие:

- нет ударной нагрузки;
- меньше риск перекоса;
- можно извлечь подшипник;
- посадку легко контролировать тестовым образцом.

Диаметр полости принят 32,30 мм. Это не универсальный допуск, а стартовое значение для FDM-печати. Конкретный принтер может потребовать 32,15; 32,40 или другую величину.

### 9.2. Верхняя посадка имеет осевую свободу

Нижняя полость имеет ширину 7,25 мм при подшипнике 7 мм. Она задаёт основное положение вращающегося корпуса по высоте.

Верхняя полость имеет ширину 7,65 мм. Дополнительный осевой зазор нужен, чтобы небольшая ошибка расстояния между посадками не заставила корпус одновременно упираться в оба наружных кольца противоположными стенками.

Иными словами, нижний подшипник определяет высоту, а верхний главным образом стабилизирует наклон и имеет небольшую возможность самоустановки по оси.

### 9.3. Винты вынесены за окружность подшипников

После перехода с 608 на 6804 прежние координаты винтов оказались внутри радиуса посадочного места. Это означало бы пересечение винта с подшипником.

В окончательной геометрии v0.2 четыре корпусных отверстия расположены при X = ±20 мм на уровнях центров подшипников. Край отверстия M4 находится снаружи полости подшипника. Вокруг отверстий сформированы отдельные бобышки.

Такое решение немного увеличивает максимальную ширину корпуса, но оно значительно понятнее и безопаснее, чем тонкие скрытые перемычки возле наружного кольца.

### 9.4. Корпус не должен стягивать наружное кольцо до овальности

Даже при правильном диаметре чрезмерная затяжка винтов может деформировать печатную полость. Поэтому половины должны смыкаться на предусмотренных опорных поверхностях. Винты не используются для «дожимания» слишком малого отверстия вокруг подшипника.

Если после затяжки вращение ухудшается, правильное действие — изменить посадочный диаметр или геометрию упоров, а не ослаблять случайные винты до неопределённого состояния.

## 10. Почему спица находится между подшипниками

Это одно из главных решений v0.2.

Если спица расположена выше верхнего подшипника, её сила создаёт не только изгибающий момент, но и дополнительную консоль над опорной базой. Верхний участок корпуса испытывает большой локальный изгиб, а подшипники нагружаются несимметрично.

Когда ось спицы находится между подшипниками:

- точка приложения нагрузки попадает внутрь опорной базы;
- расстояние до обеих опор одинаково;
- реакция распределяется симметричнее;
- уменьшается склонность верхней части корпуса к выворачиванию;
- держатель соединяется с наиболее жёсткой средней зоной корпуса;
- общая высота уменьшается.

В модели:

- нижний центр: Z = 10 мм;
- верхний центр: Z = 42 мм;
- спица: Z = 26 мм.

То есть спица расположена математически ровно посередине.

## 11. Почему спица заканчивается до древка

Спица входит сбоку и имеет глухой конец. Её ось не продолжается через центр корпуса.

Внутри центральной зоны находятся:

- древко Ø20 мм;
- подшипниковые внутренние кольца;
- металлическая распорная втулка наружным диаметром около 24 мм.

Полость корпуса под втулку имеет диаметр 24,7 мм, то есть радиус 12,35 мм. Канал спицы начинается на координате X = 15 мм. Между глухим концом канала и центральной полостью остаётся около 2,65 мм пластика.

Это расстояние выполняет несколько функций:

- исключает геометрическое пересечение;
- оставляет закрытую стенку, задающую повторяемую глубину установки;
- не позволяет спице касаться неподвижной втулки;
- предотвращает трение и передачу вращения на неподвижные детали;
- защищает углепластик от контакта с металлическим древком.

Стенка не должна воспринимать постоянную осевую нагрузку. Спица удерживается трением зажима. При сборке её не следует забивать до упора молотком.

## 12. Выбор углепластика и предварительного диаметра

Пользователь решил искать углепластиковую спицу. Это разумно по двум причинам:

- при одинаковой массе углепластик способен дать высокую изгибную жёсткость;
- малая масса уменьшает постоянный гравитационный момент и инерцию вращающейся части.

Но углепластик имеет особенности:

- плохо переносит точечное смятие;
- может раскалываться от винта с острым концом;
- не любит просверленные поперечные отверстия без специальной технологии;
- повреждение иногда проявляется внутренним расслоением, а не заметным пластическим изгибом;
- острые кромки печатного канала могут перетирать поверхность.

В v0.2 временно принят сплошной пруток Ø5 мм. Это компромиссное значение, достаточное для моделирования держателя и заметно жёстче первоначально обсуждавшейся спицы 2–3 мм.

Возможный более выгодный вариант — трубка 6 × 4 мм. При меньшей или сопоставимой массе она имеет больший момент инерции сечения. Однако её стенка чувствительнее к сжатию, поэтому зажим потребует особенно аккуратной настройки.

Окончательный диаметр нельзя выбирать только по наличию товара. Нужно учитывать:

- наружную длину около 300 мм;
- способ крепления ткани;
- допустимый прогиб;
- возможность снять флаг;
- массу прутка;
- качество поверхности;
- способность зажима удерживать его без разрушения.

## 13. Почему отказались от точечного установочного винта

В v0.1 спица фиксировалась боковым винтом M4 через термовставку. Для стальной спицы это допустимо при правильно обработанном конце винта. Для углепластика решение опасно.

Точечный винт создаёт высокое контактное давление на малой площади. Возможные последствия:

- вмятина;
- трещина матрицы;
- расслоение;
- разрушение отдельных волокон;
- постепенное ослабление при вибрации.

В v0.2 сам продольный разъём корпуса используется как зажим. В наружной части держателя половины не сходятся вплотную: между ними оставлен общий зазор 0,6 мм. Два поперечных винта M4, расположенные над и под спицей, могут уменьшить этот зазор и равномерно обжать канал.

Преимущества:

- давление распределено по длине около 40–49 мм;
- нет единственной острой точки;
- степень обжатия видна по зазору;
- зажим разборный;
- диаметр легко изменить в параметрах;
- можно использовать мягкую прокладку.

Рекомендуется надеть на зону зажима тонкую термоусадочную трубку или обернуть её полиуретановой лентой. Это увеличит трение и снизит контактные пики.

## 14. Почему противовес не включён

Противовес может компенсировать постоянный момент от собственного веса спицы и флага, но не компенсирует переменную ветровую нагрузку.

Оценим порядок величины. Сплошной углепластиковый пруток Ø5 мм длиной около 359 мм при плотности порядка 1,6 г/см³ будет весить приблизительно 11 г. Флаг площадью 0,075 м² из ткани плотностью 100 г/м² весит около 7,5 г без учёта швов.

Их суммарный гравитационный момент относительно оси будет порядка нескольких сотых ньютон-метра. Для компенсации на коротком плече потребовался бы противовес массой в десятки граммов.

Такой груз:

- увеличивает общую массу ротора;
- повышает инерцию и замедляет разворот по ветру;
- увеличивает ударные нагрузки при смене направления;
- требует дополнительного длинного рычага;
- создаёт ещё одну опасную выступающую деталь;
- не уменьшает основной ветровой момент на флаге.

Гораздо эффективнее:

- использовать лёгкую спицу;
- расположить её между двумя подшипниками;
- уменьшить лишнюю длину держателя;
- обеспечить свободное вращение;
- ограничить эксплуатацию при сильном ветре.

Противовес можно рассматривать позже только в случае, если испытания покажут нежелательное постоянное наклонное положение при полном штиле. На текущем этапе он усложняет конструкцию без достаточной пользы.

## 15. Оценка ветровой нагрузки

Точный расчёт флага сложен: ткань деформируется, складывается, поворачивается, хлопает и создаёт импульсные пики. Ниже приведена только оценка порядка величины.

Площадь флага:

`0,30 × 0,25 = 0,075 м²`.

Динамическое давление воздуха приблизительно пропорционально квадрату скорости. При плотности воздуха около 1,225 кг/м³ и условном коэффициенте сопротивления, равном единице, получаются следующие ориентиры:

- 10 м/с: сила около 4,6 Н;
- 15 м/с: сила около 10,3 Н;
- 20 м/с: сила около 18,4 Н.

Если условный центр давления находится на расстоянии 0,15 м от оси:

- 10 м/с: момент около 0,69 Н·м;
- 15 м/с: около 1,55 Н·м;
- 20 м/с: около 2,76 Н·м.

При базе подшипников 0,032 м соответствующая пара радиальных реакций имеет порядок:

- около 22 Н;
- около 48 Н;
- около 86 Н.

Для самих подшипников такие силы невелики. Но это не означает, что весь узел автоматически безопасен. Более вероятные слабые места:

- углепластиковая спица;
- печатный переход от корпуса к держателю;
- крепёж половин;
- нижний упор на древке;
- верхний M5-фиксатор;
- тонкое или мягкое древко;
- ударные пики от хлопка ткани.

Поэтому запас грузоподъёмности подшипника не заменяет испытания всей сборки.

## 16. Путь передачи нагрузки

Полезно проследить, как сила проходит через конструкцию:

1. ветер действует на ткань;
2. ткань передаёт нагрузку на углепластиковую спицу;
3. спица передаёт изгиб в длинный разъёмный зажим;
4. держатель передаёт нагрузку в среднюю часть цилиндрического корпуса;
5. корпус нагружает наружные кольца двух подшипников;
6. шарики передают реакции внутренним кольцам;
7. внутренние кольца передают радиальную нагрузку древку;
8. древко передаёт её в основную конструкцию флагштока.

Осевое усилие от собственного веса проходит преимущественно через нижний подшипник и нижний упор. Верхний подшипник стабилизирует наклон.

Резьба M5 не должна одна воспринимать весь боковой момент. При прямой схеме 6804 радиальная нагрузка передаётся через участок древка Ø20 мм. M5 только удерживает пакет от перемещения вверх.

## 17. Почему корпус разделён продольно

Разъём проходит через вертикальную ось и ось спицы. Каждая половина печатается большой плоской поверхностью на столе.

### 17.1. Прочность по слоям

После поворота детали для печати плоскости слоёв приблизительно совпадают с эксплуатационной плоскостью X–Z, в которой лежат:

- вертикальная ось древка;
- горизонтальная ось спицы;
- основная форма перехода держателя.

Это полезно для нагрузок от веса флага и многих составляющих изгиба: длинные непрерывные дорожки проходят от держателя к цилиндрическому корпусу, а не заканчиваются на одной горизонтальной межслойной границе.

При этом нельзя утверждать, что ориентация делает деталь одинаково прочной во всех направлениях. Боковая составляющая ветра может нагружать половины на раскрытие. Поэтому:

- используются поперечные винты;
- корпус имеет значительную толщину;
- подшипники и держатель зажаты между двумя симметричными половинами;
- винты пересекают слои и механически связывают их.

### 17.2. Качество внутренних поверхностей

Продольный разъём открывает:

- полуокружности посадок подшипников;
- половины канала спицы;
- центральные полости;
- отверстия под винты после ориентации.

Это уменьшает необходимость поддержек и провисающих мостов. Поверхность канала получается стабильнее, что особенно важно для углепластика.

### 17.3. Ремонтопригодность

Подшипники можно заменить без разрушения корпуса. Можно изменить прокладку спицы, осмотреть внутренние поверхности и очистить дренаж.

## 18. Геометрия держателя спицы

Держатель начинается внутри цилиндрического корпуса и выходит до X = 64 мм. Канал идёт от X = 15 до X = 64 мм, поэтому длина контакта составляет 49 мм.

Держатель имеет высоту 26 мм и половинную ширину 11,5 мм. Это даёт достаточно материала:

- над и под каналом;
- вокруг двух зажимных винтов;
- в переходе к корпусу;
- для распределения нагрузки по слоям.

Зажимные винты размещены на X = 48 мм и на высотах Z = 18 и 34 мм. Ось спицы находится на Z = 26 мм. Винты симметричны относительно спицы и не пересекают канал.

В отличие от одиночного винта, такая пара создаёт более равномерный обжим и уменьшает стремление половин перекоситься.

## 19. Корпус и дождезащита

Основной цилиндрический корпус имеет наружный диаметр около 40 мм. Ниже находится юбка диаметром около 43 мм. Верхняя часть переходит в коническую крышу.

### 19.1. Нижняя юбка

Юбка перекрывает нижнюю неподвижную опору с радиальным зазором. Она не является контактным уплотнением: между вращающейся и неподвижной деталями не должно быть трения.

В нижней зоне имеется дренажное отверстие. Его задача — дать воде выйти, если она всё-таки проникла внутрь.

### 19.2. Верхняя крыша

Коническая форма уменьшает площадь горизонтальных поверхностей, на которых задерживается вода. Центральное отверстие предназначено для прохода ступенчатого неподвижного фиксатора. Между фиксатором и печатным корпусом должен остаться небольшой лабиринтный зазор.

### 19.3. Почему не используется резиновый сальник

Контактное уплотнение добавило бы трение и могло бы мешать лёгкому развороту слабым ветром. Для небольшого узла предпочтительнее:

- подшипники 2RS;
- козырьки;
- лабиринтные зазоры;
- дренаж;
- периодический осмотр.

## 20. Крепёж корпуса

В текущей версии предусмотрено шесть поперечных винтов M4.

Четыре винта расположены возле уровней подшипников. Они:

- удерживают половины вокруг наружных колец;
- воспринимают раскрывающую нагрузку;
- связывают слои печати;
- ограничивают относительный сдвиг половин.

Два винта находятся в держателе спицы и работают как управляемый зажим.

Предпочтительна схема:

- сквозной винт;
- широкая шайба с обеих сторон;
- самоконтрящаяся гайка.

Термовставки могут сделать внешний вид аккуратнее, но для циклической уличной нагрузки сквозной винт проще проверять и надёжнее удерживается. Вставки допустимы после отдельной проработки толщины стенок и температуры их установки.

## 21. Материал печатных деталей

### 21.1. ASA

ASA рассматривается как основной практичный материал:

- лучше переносит ультрафиолет, чем обычный PLA и многие PETG;
- пригоден для улицы;
- имеет достаточную ударную вязкость;
- доступен.

Недостатки:

- склонность к короблению;
- требуется закрытый объём или защита от сквозняков;
- нужно тщательно настроить сцепление со столом.

### 21.2. PA-CF или PA-GF

Армированный полиамид может дать высокую прочность и жёсткость. Но он требует:

- сухого материала;
- износостойкого сопла;
- стабильной температуры;
- правильной ориентации;
- учёта ползучести и влагопоглощения.

Наличие углеволокна в филаменте не устраняет межслойную слабость автоматически.

### 21.3. PETG

Подходит для первого полного прототипа и тестов. Для постоянной нагретой солнцем детали необходимо учитывать ползучесть под зажатыми винтами.

### 21.4. PLA

PLA удобен для проверки формы, но не рекомендуется для постоянной улицы. Нагрев на солнце, ультрафиолет и длительная нагрузка способны привести к деформации и растрескиванию.

## 22. Рекомендуемые параметры печати

Стартовые значения для сопла 0,4 мм:

- высота слоя 0,20 мм;
- 7–9 периметров;
- 7–9 верхних и нижних слоёв;
- заполнение 45–60%;
- локальное увеличение заполнения возле держателя и винтов;
- широкий brim;
- пониженная скорость наружных стенок;
- компенсация горизонтального расширения отверстий;
- компенсация «слоновьей ноги».

Высокое заполнение само по себе не заменяет достаточное число периметров. Основные изгибающие напряжения проходят по наружным стенкам, поэтому периметры особенно важны.

## 23. Назначение тестовых образцов

Полный корпус печатать долго и дорого. Поэтому созданы два типа образцов.

### 23.1. Тест посадки 6804

Проверяет:

- фактический диаметр печатной полости;
- возможность уложить наружное кольцо без насилия;
- смыкание половин;
- влияние затяжки винтов на свободное вращение.

Если подшипник входит слишком туго, нельзя исправлять ситуацию шлифовкой одной случайной зоны или чрезмерной затяжкой. Следует изменить параметр `bearing_seat_diameter` и повторить образец.

### 23.2. Тест зажима спицы

Проверяет:

- соответствие канала фактическому диаметру углепластика;
- необходимую прокладку;
- достаточность зазора 0,6 мм;
- удержание от вытягивания;
- отсутствие повреждения после затяжки.

Испытание зажима нужно провести не только один раз. Пруток следует несколько десятков или сотен раз покачать, затем разобрать и осмотреть поверхность.

## 24. Возможные виды отказа

### 24.1. Подшипник не надевается на древко

Причины: диаметр, краска, овальность, конусность. Решение: не забивать; перейти к другой архитектуре или обработать отдельную металлическую посадочную деталь.

### 24.2. Люфт внутреннего кольца на древке

M5 не должен использоваться для «вытягивания» люфта. Потребуется точная втулка или другой подшипник.

### 24.3. Тугое вращение после сборки

Возможные причины:

- верхний фиксатор касается корпуса;
- наружное кольцо сжато;
- нет распорной втулки;
- верхняя и нижняя посадки несоосны;
- винты затянуты неравномерно;
- юбка касается нижнего упора.

### 24.4. Проскальзывание спицы

Решения по порядку:

1. проверить диаметр канала;
2. добавить тонкую мягкую прокладку;
3. равномерно увеличить затяжку;
4. увеличить длину зажима в модели;
5. только для постоянной сборки — применить совместимый клей.

Не следует сразу давить острым винтом или сверлить поперечное отверстие в углепластике.

### 24.5. Трещина в переходе держателя

Причины:

- недостаточно периметров;
- плохое межслойное сцепление;
- материал отсырел;
- слишком тонкая спица создаёт сильные удары;
- флаг оставлен при чрезмерном ветре.

### 24.6. Ослабление винтов

Использовать самоконтрящиеся гайки, широкие шайбы, метки контроля и периодический осмотр. Резьбовой фиксатор применять только совместимый с материалом гаек и разборностью.

### 24.7. Износ от воды и грязи

Проверять дренаж, состояние уплотнений 2RS и отсутствие контакта юбки с неподвижными деталями.

## 25. План испытаний

### 25.1. Проверка свободного вращения

Без флага корпус должен проворачиваться лёгким касанием и делать свободный выбег без заеданий. Проверить в нескольких угловых положениях.

### 25.2. Проверка осевого люфта

Небольшой контролируемый люфт допустим лучше, чем сильный преднатяг. Не должно быть заметного стука, но затяжка не должна тормозить подшипники.

### 25.3. Статическая нагрузка спицы

Закрепить древко вертикально. Прикладывать к концу спицы постепенно увеличиваемую нагрузку вниз и вбок. Начинать с малых значений. Измерять прогиб и осматривать корпус.

### 25.4. Циклическое испытание

Покачивать спицу в вертикальной и горизонтальной плоскостях. После нескольких сотен циклов проверить:

- винты;
- трещины;
- посадки;
- углепластик в зоне зажима;
- лёгкость вращения.

### 25.5. Испытание с тканью

Проводить сначала в контролируемом потоке или при слабом ветре, вдали от людей и имущества. Наблюдать, разворачивается ли флаг по ветру и не возникает ли устойчивое закусывание.

### 25.6. Вода

Имитировать дождь, дать воде стечь, проверить дренаж и вращение после высыхания.

## 26. Альтернативы, которые рассматривались

### 26.1. Один подшипник

Проще, но недостаточно стабилизирует длинную консоль.

### 26.2. Три и более подшипника

Повышают требования к соосности и могут увеличить трение. Не приняты.

### 26.3. Отдельная ось M8 и 608

Работоспособна при правильном адаптере, но требует больше деталей. Может стать резервной схемой, если древко не подходит под 6804. В таком случае ось должна крепиться не только тонкой M5 на изгиб, а через охватывающий древко неподвижный адаптер.

### 26.4. Вращение пластика по древку

Дешевле, но трение, износ, грязь и вода быстро ухудшат работу. Не принято.

### 26.5. Упорный подшипник

Для малой осевой массы не нужен. Радиальные глубококанавочные подшипники воспринимают умеренную осевую нагрузку. Дополнительный упорный узел увеличит число деталей и трение.

### 26.6. Противовес

Компенсирует только вес, но увеличивает инерцию и не решает ветровую нагрузку. Не принят.

### 26.7. Точечный винт в углепластик

Создаёт риск смятия и расслоения. Заменён протяжённым разъёмным зажимом.

## 27. Что должно измениться после получения древка

Следующая версия должна начинаться не с декоративной формы, а с измерений.

Древко получено и измерено; значения находятся в карточке [#015](catalog/catalog.html#component-015). Использовать 6804 непосредственно на древке нельзя. Выбранный кандидат указан в [#008](catalog/catalog.html#component-008). Заготовка двух жёстких переходных втулок PETG и независимых пробников уже создана как [#401](mechanical/docs/PETG_6806_BEARING_ADAPTER_RU.md), но не генерировалась. §bearingadapter1

Для нижнего торца разборной секции отдельно подготовлена source-only
заготовка [#402](mechanical/docs/LOWER_POLE_CABLE_STRAIN_RELIEF_RU.md): закрытая
TPU85-разгрузка с двумя каналами под отдельные жилы, защищающая провод между
M125 и аккумулятором. Она не генерируется до измерения торца и стыка секций.
§lowercablestrain1

Нужно определить:

1. какие варианты #40101–#40103 дают правильную посадку на древко;
2. какие варианты #40104–#40106 дают правильную посадку во внутреннее кольцо 6806;
3. где находятся нижний и верхний осевые упоры внутренних колец;
4. как устроена резьба M5 и какой высоты должен быть верхний фиксатор;
5. остаётся ли достаточная стенка нового ротора вокруг наружного кольца 6806;
6. какой углепластик куплен;
7. какой размер канала даёт тестовая печать.

Возможны три сценария.

### Сценарий A: древко действительно точное Ø20 и имеет уступ

Сохраняется основная архитектура v0.2. Корректируются только допуски, верхний фиксатор и наружная форма.

### Сценарий B: диаметр близок к 20, но посадка непригодна

Добавляется точная металлическая или жёсткая разрезная втулка, либо выбирается подшипник другого внутреннего диаметра. Нельзя компенсировать большой люфт мягкой лентой внутри подшипника.

### Сценарий C: верх древка короткий, конический или сложной формы

Потребуется неподвижный колпачок-адаптер, который охватывает древко и несёт отдельную металлическую ось. Тогда можно вернуться к подшипникам 608 или выбрать другую пару, но спица всё равно должна оставаться между подшипниками и заканчиваться до оси.

## 28. Итоговая логика v0.2

Конструкция сделана простой не за счёт удаления необходимых функций, а за счёт правильного разделения задач:

- два подшипника отвечают за вращение и устойчивость;
- древко Ø20 воспринимает радиальную нагрузку;
- M5 отвечает только за осевое удержание;
- металлическая втулка передаёт усилие затяжки между внутренними кольцами;
- печатный корпус удерживает наружные кольца;
- продольный разъём обеспечивает правильную печать и обслуживание;
- протяжённый зажим удерживает углепластик без точечного повреждения;
- спица находится внутри опорной базы и не пересекает центр;
- противовес и лишние подшипники не добавлены без доказанной необходимости.

Это хорошая базовая архитектура для следующего этапа. Но окончательная надёжность будет определяться точностью реального древка, качеством верхнего и нижнего неподвижных упоров, выбранной спицей и результатами испытаний.

# Дополнение v0.5: переход на оранжевый PETG и белый TPU 95A

## Разделение функций материалов

В версии v0.5 материалы используются не как взаимозаменяемые, а по разным функциям:

- PETG образует силовой каркас, посадки подшипников, винтовые бобышки, электронный отсек, крышку и неподвижный воротник;
- TPU 95A используется только для распределения прижима, уплотнения и разгрузки кабелей.

Такой подход предотвращает потерю соосности: мягкий материал не находится в силовой цепи подшипников.

## Почему вкладыш спицы сделан отдельным

Углепластиковая трубка чувствительна к точечному давлению и острым кромкам. Полукруглый TPU-вкладыш распределяет усилие по длине 51 мм. Два фланца исключают продольное смещение, а ключи удерживают половины при обслуживании.

## Почему прокладка крышки имеет лапки

Съёмная крышка обслуживается чаще других деталей. Незакреплённая прокладка легко выпадает, перекручивается или загрязняется. Поэтому прокладка находится в пазу и имеет четыре монтажные лапки. Клей является дополнительным, а не основным удержанием.

## Почему втулка M125 имеет фланец

Полый шток позволяет спрятать M125, но гладкая цилиндрическая втулка могла бы провалиться вниз. Верхний фланец лежит на торце трубы и зажимается неподвижным воротником. Токосъёмник остаётся съёмным и не заливается компаундом.

## Почему белый TPU не оставлен снаружи

Белый TPU быстро загрязняется, а его долговечность на открытом солнце зависит от конкретной рецептуры. Все основные белые детали закрыты PETG-корпусом, крышкой или металлическим древком.

## Почему конструкция изменена под PETG

Для PETG увеличены толщины стенок, добавлены плавные переходы и сохранена продольная печать половин. Силовой крепёж выполняется сквозными винтами с шайбами. Это уменьшает влияние ползучести PETG под постоянным локальным давлением.

## Почему используются тестовые купоны

Точный размер отверстий FDM зависит от потока, температуры, скорости и компенсаций конкретного принтера. Поэтому номинальная модель не считается доказательством посадки. В архиве есть три диаметра посадки 6804 и три наружных диаметра втулки M125.

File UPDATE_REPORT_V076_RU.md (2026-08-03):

# Подробный отчёт по кумулятивному обновлению v0.7.6

## 1. Основание и границы

Пакет подготовлен для `kva4991/flagpole` на базе `main` commit `14346190d702c292fded598f55fc431dd92b19ad`, версия источника — v0.7.5.

Обновление затрагивает:

- публичное имя проекта;
- представление ID в карточках и полноэкранном 3D;
- автоматическое размещение двухмерных выносок;
- компоновку трёх одно-материальных очередей печати;
- трактовку PETG-подложек/brim/raft;
- минимальный точный CAD-процесс build123d-mcp;
- документацию, ADR, тесты, производные изображения/GLB и контрольные суммы.

Электрическая схема, маршрут проводов, размеры корпуса, световой тоннель, мембрана, лямки, количество закладных, прошивочный BLE-протокол и физические посадки этой задачей не пересматриваются.

## 2. Публичное имя и техническая совместимость

### Изменено

`projectDisplayName` становится:

```text
Super_pommels_and_flag
```

Имя используется в каталоге, Android resources/Kotlin и видимой документации.

### Совместимость и Android package

```text
bluetoothDeviceName = Crucian
applicationId = ru.superpommelsandflag.crucian
android/crucian-control/
electronics/firmware/esp32_c3_crucian_v06/
```

BLE-имя и исторические пути проектов сохранены для совместимости. Android `applicationId`, `namespace` и Kotlin package по требованию владельца адаптированы к `ru.superpommelsandflag.crucian`: нижний регистр без подчёркиваний. Это означает установку как отдельного приложения относительно старого `ru.quicktickets.crucian`.

## 3. Миниатюры без ID

Ранее overlay-чертежи использовали `annotatedPreview` одновременно как полноразмерный файл и изображение карточки. В 3D-карточках hotspots также отображались сразу после загрузки модели.

Принято:

- схема `catalog/drawings.json` повышена с 3 до 4, потому что чистая миниатюра стала обязательной частью контракта;
- у каждой 2D-карточки есть отдельное поле `thumbnail`;
- overlay-карточка показывает чистый `preview`, а по нажатию открывает `annotatedPreview`;
- разнесённый вид 112 использует чистый `preview_v06_exploded_PETG_TPU.png`;
- таблица ID 117 использует нейтральную проектную SVG-миниатюру без номеров;
- hotspots остаются в DOM карточного `<model-viewer>`, но скрыты CSS;
- легенда ID под карточкой сохраняется: она не перекрывает изображение и нужна для навигации.

Валидатор каталога отклоняет `thumbnail`, ссылающийся на `catalog/annotated/` или файл `_ids.png`.

## 4. Кнопка ID в полноэкранном просмотре

В верхней панели рядом с круглым крестиком добавлена отдельная нарисованная SVG-кнопка:

- пиктограмма глаза;
- подпись `ID`;
- состояние `aria-pressed`;
- динамические `title` и `aria-label`;
- перечёркнутый глаз при скрытых метках.

При открытии непечатной модели метки по умолчанию видимы. Нажатие переключает CSS-класс `ids-hidden` без повторной загрузки GLB. Для печатных раскладок, у которых hotspots отсутствуют, кнопка скрыта. Состояние сбрасывается при закрытии или выходе из Fullscreen API.

## 5. Более короткие двухмерные выноски

### Было

`labelPosition` являлся абсолютным центром рамки. Во многих карточках он находился у края листа, поэтому лидер шёл через половину схемы и мог пересекать другие элементы.

### Стало

`labelPosition` используется только как предпочтительное направление. Resolver:

1. строит несколько колец кандидатов вокруг `target`;
2. ставит плотные группы первыми;
3. штрафует пересечение рамок;
4. штрафует попадание линии через чужую рамку;
5. штрафует пересечение уже размещённых лидеров;
6. мягко штрафует прохождение через контрастные контуры исходного чертежа, кроме зоны у самой цели;
7. выбирает ближайшую допустимую рамку;
8. начинает линию на ближайшей границе рамки, а не из её центра.

Результат детерминирован и не зависит от системного шрифта. Генерируется `mechanical/CALLOUT_LAYOUT_REPORT_V076.json` с прежней и новой нормированной длиной лидеров, пересечениями и фактическими координатами. `--check` сравнивает как PNG, так и отчёт.

**Почему не перенесены вручную десятки `labelPosition`:** ручные координаты снова устареют после изменения чертежа. Resolver сохраняет намерение «с какой стороны лучше подписать», но адаптирует расстояние автоматически.

## 6. Компактные очереди печати

### Проблема

`generate_models_v06.py` хранил большие списки ручных XYZ-позиций. Между деталями оставались пустые зоны, а изменение габарита не приводило к автоматической перепроверке стола.

### Решение

Добавлен `mechanical/layout_packing.py`:

- работает с уже выбранной ориентацией печати;
- использует AABB фактической сетки;
- стол — 256 × 256 мм;
- резерв от края — 8 мм;
- PETG — минимум 6 мм между AABB;
- TPU 95A/85A — минимум 5 мм;
- крупные детали размещаются первыми по детерминированным полкам;
- итоговая сцена центрируется для удобного просмотра;
- при переполнении стола генерация завершается ошибкой;
- метрики записываются в `model_parameters_and_diagnostics_v06.json`.

**Почему зазор не сделан нулевым:** «ближе» не означает касание. Нужен запас от brim, неточности габарита и удобство выделения объектов в слайсере.

## 7. Что решено по PETG-подложкам

В текущем наборе печатных деталей отдельной жертвенной PETG-подложки под TPU нет. Ранее документация оставляла общее «допустимое исключение», которое можно было принять за уже спроектированную деталь.

Зафиксировано:

- `#petg-5` — реальная сервисная крышка, сопрягаемая с `#tpu85-1`, а не подложка для печати;
- TPU печатается отдельными очередями и устанавливается после печати;
- brim/raft создаётся профилем слайсера и не является каноническим физическим компонентом;
- добавлять фиктивную пластину в STL/GLB запрещено, потому что её можно ошибочно включить в BOM или напечатать как часть изделия;
- в карточках очередей это объясняется прямо.

То есть отсутствие подложек в прежних изображениях было не пропущенной геометрией, а неточной формулировкой документации. В v0.7.6 формулировка исправлена.

## 8. Какие CAD-навыки добавлены

Добавлен только процесс, который закрывает реальный пробел текущего проекта:

```text
pzfreo/build123d-mcp
modeling
drawing
repair
```

В репозитории сохранены:

- `mechanical/docs/BUILD123D_MCP_WORKFLOW_RU.md`;
- пример безопасной конфигурации `tools/cad/build123d-mcp.example.json`;
- короткая ссылка и обязательные границы в `AGENTS.md`;
- ADR-0029.

Не добавлены как обязательные:

- `text-to-cad` — дублирует проектную дисциплину `AGENTS.md`;
- `draftwright` — рассматривается после появления устойчивых STEP;
- `blender-industrial-kit` — Blender остаётся визуализатором, не производственным источником.

Пилот ограничен `#petg-6`, `#petg-10`, `#petg-5`. Существующий SDF/trimesh-генератор остаётся каноническим до отдельного принятия каждого B-Rep-переноса.

## 9. Версия

Версия повышается до v0.7.6. Причина — изменяются публичная идентичность, HTML-интерфейс, правила медиа, алгоритм аннотаций, GLB-раскладки, диагностические JSON, документация и quality gate. Сохранение v0.7.5 создало бы два несовместимых набора производных файлов под одним номером.

Технические имена файлов `v0_6` и текущие скрипты с суффиксом `v075` сохраняются для совместимости ссылок; их содержимое и метаданные соответствуют v0.7.6.

## 10. Новые долгосрочные решения

- ADR-0027 — чистые миниатюры, полноэкранный переключатель и auto-near-target callouts;
- ADR-0028 — компактные одно-материальные раскладки и отсутствие фиктивных PETG-подложек;
- ADR-0029 — ограниченный build123d-mcp CAD-контур.

## 11. Тесты

Добавлены:

- `catalogPresentationV076.test.mjs` — чистые миниатюры, публичное имя, кнопка ID и отчёт выносок;
- `printLayoutPolicyV076.test.mjs` — границы стола, зазоры и отсутствие backing geometry;
- `cadWorkflowV076.test.mjs` — только необходимые MCP-навыки и пилотные ID;
- `layout_packing.py --self-test`;
- `render_catalog_part_callouts_v075.py --self-test`.

`quality:gate` запускает оба Python self-test до каталоговых и Node-проверок. Дополнительно до упаковки выполнено двукратное применение к полному синтетическому checkout: первый запуск изменил источники и создал ZIP, второй не изменил ни одного файла (`changedPaths = 0`). Отдельно проверено, что исторические CI-свидетельства v0.7.5 не переименовываются в v0.7.6.

## 12. Порядок применения и регенерации

Применитель:

1. проверяет checkout и base commit;
2. обновляет только источники и документацию;
3. запускает identity generator;
4. полностью пересобирает механику и три GLB-раскладки;
5. пересобирает превью, схемы и компактные ID-выноски;
6. генерирует HTML;
7. обновляет SHA-256;
8. записывает честный текущий статус: локальный quality gate отдельно, исторический CI v0.7.5 отдельно, новый CI — pending до push владельца;
9. повторно запускает quality gate и `git diff --check` после обновления статуса, manifest и SHA-256;
10. создаёт полный `Super_pommels_and_flag_v0.7.6_cumulative_full.zip` из checkout.

Скрипт не выполняет `git add`, commit или push.

## 13. Ограничения

- Self-test пакета проверяет алгоритмы и идемпотентность, но не заменяет запуск на полном checkout.
- Финальные PNG/GLB и полный ZIP появляются после применения к локальному клону, потому что неизменённые бинарные файлы не дублируются в update bundle.
- Проверки сеток не подтверждают реальные посадки, прочность, герметичность, нагрев или печатный профиль.
- Build123d-процесс добавлен, но существующие 23 детали автоматически не конвертированы в B-Rep.
- Смена Android application ID создаёт отдельное приложение; автоматического переноса данных со старого package нет.
## 14. Контроль ложных заявлений о проверке

Глобальная замена `0.7.5 → 0.7.6` намеренно не применяется к `VALIDATION_STATUS_RU.md`, `docs/current-implementation-status.ru.md`, старым отчётам, архивным ADR и предыдущему manifest. После локального запуска применитель формирует новый статус отдельно. Поэтому успешный GitHub Actions run `30761888122` остаётся доказательством опубликованной v0.7.5, а не выдаётся за ещё не опубликованную v0.7.6.

`PROJECT_MANIFEST.json` сохраняет прежние `publication`/`validation` в полях `previousPublication` и `previousValidation`, пересчитывает file-count/bytes/largest-files по фактическому checkout и помечает новый GitHub Actions как ожидающий push владельца.

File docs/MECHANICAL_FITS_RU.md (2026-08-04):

# Откуда берутся окончательные механические посадки

Окончательные посадки нельзя честно получить только из:

- названия подшипника;
- картинки продавца;
- номинального диаметра штока;
- размеров в чужой модели;
- универсальной таблицы допусков для литья или металлообработки.

Для FDM-печати посадка является результатом четырёх факторов:

```text
фактическая деталь
+
геометрия модели
+
конкретный материал
+
конкретный профиль печати и ориентация
```

## 1. Что измеряется физически

### Шток

Принятые рабочие наружный и внутренний диаметры одного сечения и рассчитанная стенка хранятся только в карточке [флагштока #015](../catalog/catalog.html#component-015). Овальность отдельно не закладывается в CAD. Жёсткая PETG-втулка и её независимые посадочные пробники заданы в [карточке #401](../mechanical/docs/PETG_6806_BEARING_ADAPTER_RU.md); TPU между PETG и древком не применяется. §physicalcomponents1 §bearingadapter1

- соответствие короткой пробной втулки фактической зоне установки;
- длина доступного прямого участка;
- краска, шов и заусенцы, мешающие надеванию втулки.

### Подшипниковый узел

6804-2RS отклонён как несовместимый. Выбранный кандидат и его стандартные размеры указаны в карточке [подшипника #008](../catalog/catalog.html#component-008). Заготовка переходной втулки #401 уже отделяет посадку на древко от посадки в подшипник; наружный диаметр нового подшипника нельзя переносить в ротор без проверки толщины стенок и общего габарита навершия.

- наружный диаметр;
- внутренний диаметр;
- ширина;
- фактическая посадка пробников серии B во внутреннем кольце и отсутствие качания;
- ручная сборка выбранной пары «древко — PETG-втулка — внутреннее кольцо» без сдавливания трубы.

### Токосъёмник M125

- корпус;
- фланец;
- выступ ротора;
- длина;
- пучок проводов.

### Спица

- Ø5 мм является заказным номиналом;
- фактический диаметр измеряется минимум в трёх местах и двух направлениях.

### Крепёж

- размер гайки по граням;
- толщина;
- диаметр и реальная головка винта.

### Электронные платы

- длина, ширина, максимальная высота;
- выступающие разъёмы;
- зоны антенны и датчиков.

## 2. Как учитывается Bambu Lab X1 Carbon

Все купоны и окончательные детали должны печататься:

- на том же Bambu Lab X1 Carbon;
- соплом 0,4 мм;
- из той же катушки оранжевого PETG;
- с тем же профилем потока, температурой и компенсацией отверстий;
- в той же ориентации слоёв, что и соответствующий участок корпуса.

Купон, напечатанный другим материалом или другой ориентацией, не подтверждает посадку корпуса.

## 3. Какие купоны уже есть

### Подшипник

Существующие купоны ниже являются историческими купонами посадки наружного кольца 6804. Для нового подшипника подготовлены, но ещё не сгенерированы независимые серии #40101–#40106 из [единого файла размеров](../mechanical/cad_drafts/petg_6806_adapter_v076.json).

```text
32,20 мм
32,35 мм
32,50 мм
```

Выбирается вариант, который:

- принимает подшипник без молотка;
- не создаёт овальность после стяжки половин;
- не позволяет кольцу заметно перемещаться.

### Втулка M125

```text
15,60 мм
15,80 мм
16,00 мм
```

### Закладная M4

```text
PETG_M4_captive_nut_trap_coupon.stl
```

### Утончения под сверление

```text
PETG_drill_skin_0.6_0.8_1.0_coupon.stl
```

### Прокладки

Парные PETG/TPU-купоны крышки и втулок.

## 4. Когда размер считается подтверждённым

Размер получает статус «подтверждён» только после:

1. измерения реальной детали;
2. печати купона;
3. полного остывания купона;
4. пробной сборки;
5. повторной проверки после 24 часов под нагрузкой;
6. записи результата в `MEASUREMENTS_REQUIRED_RU.md` и параметры генератора.

До этого он остаётся предварительным.

## 5. PETG сейчас и ASA позже

Текущая сборка печатается из купленного оранжевого PETG. Все текущие посадки подбираются под него.

Если позднее появится бюджет на ASA, нельзя просто напечатать те же файлы и считать посадки одинаковыми. Необходимо:

1. выбрать конкретную ASA;
2. высушить и настроить её профиль;
3. повторить посадочные купоны;
4. изменить компенсации генератора;
5. только затем перепечатать наружные жёсткие детали.

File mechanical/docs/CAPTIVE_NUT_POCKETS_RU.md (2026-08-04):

# Обслуживаемые закладные гайки v0.7.6

## Полный перечень

- 8×M4: шесть стягивают ротор, две зажимают втулку спицы;
- 4×M3: сервисная крышка;
- 2×M3: климатический карман;
- 2×M3: неподвижный воротник;
- 2×M3: съёмная опора VEML7700.

Всего: 8×M4 и 10×M3.

Каждый карман имеет шестигранную посадку и доступ для замены гайки. Гайки не должны перекрывать сухой контур прокладки, кабельную дорожку, воздушную камеру датчика или оптический проход.

Четыре гайки крышки и две гайки крепления `#petg-8` опускаются сверху в
глухие колодцы после снятия соответствующей детали. Под гайкой остаётся только
короткое глухое углубление для конца винта. Боковых загрузочных окон во внешней
стенке корпуса у этих шести закладных нет. Остальные M4/M3 сохраняют
обслуживаемые горловины там, где они не образуют отверстие в электронном боксе.

Стойки четырёх винтов сервисной крышки выполнены как внутренние цилиндрические
колодцы диаметром 10 мм и высотой 18 мм. Они формируются после полости
электронного бокса, поэтому сохраняют полное сечение и длинную опору внутри
корпуса вместо тонкого наружного выступа. Усиление уменьшает риск отрыва при
затяжке, но не отменяет ограничения момента для крепежа M3.

Во внутренней центрирующей юбке сервисной крышки напротив этих стоек сделаны
локальные выборки диаметром 10,5 мм. Выборки заканчиваются у нижней плоскости
жёсткой пластины крышки и не проходят наружу.

Оси четырёх винтов находятся в наружной «мокрой» зоне на ±31 мм от центра бокса
по длине и ±16 мм по ширине. Внутренний замкнутый контур прокладки проходит
между винтами и электроникой; генератор проверяет отсутствие пересечения
канавки с винтовыми отверстиями. Вода в отверстии остаётся за прокладкой и
упирается в глухое дно колодца. Разрывать уплотнительный контур нельзя.

## Номинальные параметры

- M4: гайка 7,0 мм по граням, карман 7,30 мм;
- M3: гайка 5,5 мм по граням, карман 5,80 мм.

Зазор 0,30 мм является исходным параметром, а не подтверждённой посадкой.

## Обязательные купоны

- `PETG_M4_captive_nut_trap_coupon.stl`;
- `PETG_M3_captive_nut_trap_coupon.stl`.

Проверить запрессовку, удержание при затяжке, проворот, растрескивание PETG,
достаточную глубину глухого колодца и извлечение гайки для обслуживания. Не
использовать саморезы непосредственно в PETG как замену закладным.

Карта: `mechanical/fastener_captive_nut_map_A4_landscape.svg`.

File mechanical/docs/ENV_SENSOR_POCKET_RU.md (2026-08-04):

# Съёмный карман AHT20+BMP280 v0.7.6

<!-- §envmech1 -->

## Мембрана

Карман рассчитан на найденную самоклеящуюся мембрану:

- полный наружный диск и функциональная центральная область — по карточке мембраны [#019](../../catalog/catalog.html#component-019); §physicalcomponents1
- посадочная площадка — Ø20,4 мм;
- наружный капельник — только 1,0 мм высотой, Ø22,0/20,8 мм;
- в капельнике четыре сливных разрыва, поэтому он не образует чашу;
- защитный бортик — Ø23 мм с нижними дренажными разрывами;
- отдельная TPU-прокладка мембраны не применяется.

В корпусе предусмотрена остаточная кожа 0,8 мм. После печати сверлятся семь отверстий Ø2 мм: одно центральное и шесть по окружности R3,2. Все отверстия должны находиться внутри активной области, размер которой берётся из карточки [#019](../../catalog/catalog.html#component-019). Суммарная открытая площадь отверстий около 22 мм².

Активный центр нельзя покрывать RTV. Наружный край наклейки допускается обрезать, но нельзя нарушать рабочую область и клеевое кольцо.

## Внутреннее устройство

- плата стоит на опорах;
- смещённая перегородка исключает прямой сквозной продув BMP280 и прямую струю воды;
- четыре I²C-провода проходят через отдельный potting-well Ø8 мм;
- герметик заполняет только кабельный колодец;
- корпус кармана уплотняется TPU85-прокладкой 1,6 мм с проектным сжатием до 1,2 мм;
- два M3 крепят карман в обслуживаемые закладные корпуса.

## Проверка

Сравнить отклик температуры, влажности и давления без мембраны и после установки. Провести полив, конденсационный цикл и проверку восстановления показаний после высыхания.

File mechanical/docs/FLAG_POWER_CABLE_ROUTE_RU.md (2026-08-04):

# Наружный маршрут двух проводов питания флага v0.7.6

<!-- §flagpower1 -->

## Решение

Два отдельных провода номинального диаметра 2 мм не проходят через спицу и не пересекают посадки подшипников. От герметичного 2-pin разъёма возле флага они входят в сменную TPU95-направляющую `#tpu95-10`, расположенную в отмеченной владельцем точке и наклонённую на 34,99° вниз к флагу.

Далее провода идут по открытой приподнятой PETG-дорожке:

- чистый просвет между бортами — 4,2 мм;
- высота бортов — 2,5 мм;
- номинальная толщина каждого провода — 2 мм;
- крепёж M4 и его закладная остаются выше трассы;
- маршрут имеет наружную низкую точку для стока воды;
- вход в сухой электронный бокс единственный: разрезная манжета `#tpu95-3/#tpu95-4`;
- внутри бокса рывок принимает `#petg-9`, а до клемм оставляется сервисная петля.

## Почему направляющая сменная

Цельная `#tpu95-10` защищает изоляцию от края PETG и задаёт поворот примерно
35° вниз к флагу. Её посадочное кольцо находится на нижнем скруглении
`#petg-2`, которое обхватывает шток: начало оси `[15,2; -17,2; 4,8]` мм,
наружный конец `[29,2; -17,2; -5,0]` мм. От посадки внутрь ротора выполнен
непрерывный проход, а внутренняя открытая дорожка доведена до его входа.
Направляющая неразрезная и содержит два закрытых сквозных канала; провода
протягиваются до установки разъёма.

## Перед полной печатью

1. Измерить оба провода в трёх местах.
2. Напечатать `PETG_twin_wire_rail_4.2x2.5_coupon.stl`.
3. Проверить минимальный радиус изгиба у `#tpu95-10`.
4. Проверить доступ к M4 при уложенных проводах.
5. Провести вибрационный, рывковый и дождевой тест.

Чертёж: `mechanical/flag_power_cable_route_A4_landscape.svg`.

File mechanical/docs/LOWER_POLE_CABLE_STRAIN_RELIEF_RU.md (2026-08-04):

# Нижняя гибкая втулка-разгрузка кабеля

<!-- §lowercablestrain1 -->

## Результат

Для нижнего торца секции флагштока принята заготовка цельной детали `#tpu85-4`
из TPU 85A. Она защищает кабель между токосъёмником M125 и аккумулятором при
сборке и разборке древка. Сейчас существует только размерный источник [#402](../cad_drafts/tpu85_lower_pole_strain_relief_v076.json)
и opt-in build123d-исходник; STL, STEP, GLB и изображение не создавались.

## Почему выбрана такая форма

Обычная короткая шайба защищает изоляцию от кромки, но переносит перегиб в одно
место. Жёсткий ввод передаёт рывок прямо на пайку или токосъёмник. Поэтому узел
состоит из трёх последовательно работающих зон:

1. внутренний посадочный стакан с шестью округлыми рёбрами удерживается в трубе;
2. внутренний плавный переход отделяет кабель от металлического торца без наружной губы;
3. длинный конический хвост с тремя неглубокими гофрами постепенно изгибается
   во все стороны и затем возвращается.

Деталь закрытая, без продольного разреза и без торцевой губы: вся посадочная
часть скрыта внутри трубы. Две отдельные жилы Ø2 мм проходят в
двух соседних закрытых каналах; общий принятый габарит пары — 4 мм. Жилы
продеваются до установки разъёма или оконцевания. Это уменьшает риск раскрытия шва при циклическом
изгибе и исключает прямой путь к металлической кромке.

## Что втулка делает и чего не делает

Втулка распределяет перегиб, гасит короткий рывок и не позволяет кромке трубы
резать оболочку. Она не должна удерживать вес разъединённой секции и не может
компенсировать произвольное вытягивание кабеля. Над ней требуется свободный
запас провода; стартовое значение находится только в JSON #402 и уточняется
после пробной сборки.

Каждая жила удерживается своим округлым каналом. Одно общее отверстие Ø4 мм не
применяется: в нём пара могла бы смещаться, тереться и передавать рывок только
на одну жилу. Принятые Ø2 мм пока считаются исходным допущением владельца и
позднее подтверждаются штангенциркулем.

## Почему TPU 85A

Здесь мягкость задаёт не соосность и не силовую посадку, а циклическую
деформацию. TPU 85A лучше TPU 95A распределяет малые изгибы по длинному хвосту.
Посадочная часть остаётся достаточно длинной и использует несколько невысоких
рёбер, чтобы не давить одной линией на тонкий металл.

## Перед генерацией

Диаметр нужной секции подтверждён одинаковым по всей длине; внутренний размер
берётся только из [карточки #015](../../catalog/catalog.html#component-015).
Перед генерацией остаётся определить:

- свободную глубину до элемента телескопического/резьбового стыка;
- какая зона внутри трубы занята соединением секций;
- подтвердить Ø2 мм каждой жилы и габарит пары 4 мм;
- доступный свободный запас провода между M125, втулкой и аккумулятором.

Размеры покупных частей не дублируются здесь: см. [древко #015](../../catalog/catalog.html#component-015)
и [провод #022](../../catalog/catalog.html#component-022). §physicalcomponents1

## Пробники и принятие

Серия `#40201`–`#40203` проверяет шесть рёбер Ø24,5/24,7/24,9 мм на свободном
теле Ø24,0 мм; стартовый вариант — Ø24,7 мм. При избыточном натяге владелец
может аккуратно и равномерно подрезать только вершины рёбер. Серия
`#40204`–`#40206` выбирает только мягкое удержание двух жил каналами
Ø1,8/2,0/2,2 мм. Центры обеих серий
надо пересчитать после измерений, а не печатать текущие числа как окончательные.

После выбора посадок напечатать целую втулку и проверить не менее 100 ручных
циклов изгиба, возврат формы, отсутствие надреза оболочки и полное закрытие
стыка секций. Только после этого разрешается добавить `#tpu85-4` в канонический
реестр печатных деталей.

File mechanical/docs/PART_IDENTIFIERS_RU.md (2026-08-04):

# Идентификаторы печатных деталей v0.7.6

<!-- §partid1 -->

Текущий реестр находится в `mechanical/part_id_registry_v06.json` и отображается в `mechanical/part_id_table_v06.svg`.

Новые жёсткие детали:

- `#petg-9` — съёмный двухуровневый каркас электроники;
- `#petg-10` — съёмная опора VEML7700 на двух M3.

`#tpu95-10` — цельная сменная направляющая с двумя закрытыми сквозными каналами, установленная на нижнем скруглении `#petg-2` под углом около 35° вниз к флагу. Провода продеваются до установки разъёма.

Ключевые конструктивные элементы имеют дочерние feature-ID из
`mechanical/feature_id_registry_v076.json`; например,
`#petg-2_закладная1`, `#petg-6_клеевая_полка` и
`#tpu95-10_канал1`. Они используются в полноэкранных выносках, но не создают
новые позиции BOM.

Отдельная TPU85-прокладка мембраны удалена: самоклеящаяся мембрана Ø20 устанавливается непосредственно на ровную PETG-площадку. Текущая таблица содержит 10 PETG, 10 TPU95 и 3 TPU85 позиции.

При изменении состава нужно одновременно обновить генератор, STL, реестр, таблицу, разнесённые виды, каталог и тесты.

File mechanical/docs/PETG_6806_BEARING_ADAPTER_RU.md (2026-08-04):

# Переходная втулка PETG для 6806-2RS и посадочные пробники

<!-- §bearingadapter1 -->

## Статус

Создана только параметрическая заготовка. STL, STEP, GLB и изображения не генерировались. Карточка исходной заготовки показывается в разделе «Чертежи и 3D» локального каталога как `#401`.

## Источники размеров

- Физические размеры подшипника находятся только в карточке [#008](../../catalog/catalog.html#component-008).
- Физические размеры древка находятся только в карточке [#015](../../catalog/catalog.html#component-015).
- Все размеры финальной печатной детали и пробников находятся в [`mechanical/cad_drafts/petg_6806_adapter_v076.json`](../cad_drafts/petg_6806_adapter_v076.json).
- Воспроизводимая build123d-заготовка: [`mechanical/generate_petg_6806_adapter_coupons_v076.py`](../generate_petg_6806_adapter_coupons_v076.py).

Физические размеры покупных деталей здесь намеренно не копируются. Численные размеры печатной геометрии не дублируются в этом документе: сайт и будущий генератор читают один JSON-файл детали.

## Конструкция

Для двух подшипников предусмотрены две одинаковые жёсткие втулки из PETG. Каждая заполняет радиальный промежуток между наружной поверхностью древка и внутренним кольцом подшипника. Между PETG и металлом нет слоя TPU: мягкий промежуточный слой ухудшил бы соосность и добавил бы ползучесть.

Втулка не должна выправлять древко усилием запрессовки. Осевое удержание внутренних колец и втулок должно выполняться жёсткими упорами будущего центрального узла, а не одним трением.

## Почему две независимые серии пробников

Серия `P` проверяет только внутреннюю посадку на древко. Серия `B` проверяет только наружную посадку во внутреннем кольце подшипника. Это позволяет не смешивать две погрешности FDM в одном пробнике. После примерки выбранные значения переносятся в `finalPart`, статус меняется на разрешённый, и только после этого допускается генерация финальной пары.

Файлы различаются обозначениями `P1…P3` и `B1…B3`; наносить размерную надпись на функциональную поверхность нельзя.

## Критерии примерки

- только равномерное ручное усилие, без молотка и нагрева подшипника;
- отсутствие качания на древке и во внутреннем кольце;
- отсутствие заметного сдавливания тонкой трубы;
- отсутствие беления, трещин и расслоения PETG;
- повторяемость результата на обеих фактических опорах.

## Запуск в будущем

До отдельного разрешения владельца команду не выполнять. После разрешения запускать только из защищённой копии `pesochnica`:

```powershell
python mechanical/generate_petg_6806_adapter_coupons_v076.py --generate-coupons
```

Параметр `--generate-final` намеренно заблокирован в JSON до записи результатов купонов.

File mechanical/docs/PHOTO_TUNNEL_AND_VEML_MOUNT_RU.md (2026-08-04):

# Световой тоннель и крепление VEML7700 v0.7.6

<!-- §lightwell1 -->

## Тоннель

Текущий вариант:

- наружный цилиндр Ø11 мм;
- длина 15 мм;
- оптический проход Ø4,2 мм;
- внутренняя полка Ø16 × 2,2 мм;
- кольцевой резервуар клея Ø12,2–14,2 мм;
- глубина резервуара 0,45 мм.

Клей наносится только в кольцевую зону внутренней полки. Оптический проход, окно и активную поверхность VEML7700 герметиком не покрывать.

Купон `PETG_photo_tunnel_15_18_comparison_coupon.stl` позволяет сравнить тоннели 15 и 18 мм. До стенда 15 мм является текущим выбором, а не подтверждённым оптимумом.

## Окно

Прозрачное окно вырезается из фактически имеющегося материала. Толщина измеряется до корректировки посадки. После установки окна, прокладки, прижима и матирования внутренней поверхности нужно повторно выполнить DAY/NIGHT-калибровку.

## Опора платы

Съёмная PETG-опора `#petg-10` крепится двумя M3 в обслуживаемые
закладные и прижимает плату снизу к четырём угловым площадкам. Центрального
сквозного отверстия в опоре нет: оно не является оптическим проходом, потому
что между опорой и тоннелем находится сама плата. Оптический проход относится
только к крышке и `#petg-6`. Предварительный просвет платы — 17,1 × 17,1 мм;
два конических штырька имеют шаг 11 мм. Эти размеры необходимо сверить с
фактической платой и купоном.

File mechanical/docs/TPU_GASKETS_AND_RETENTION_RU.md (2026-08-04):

# Белые детали из TPU 95A: назначение, удержание и приклеивание

## 1. Общий принцип

Белый TPU 95A используется только там, где нужна контролируемая упругость. Все TPU-детали имеют механическое удержание и не должны зависеть только от клея.

Белый материал желательно скрывать внутри корпуса или под козырьками. Это уменьшает загрязнение и воздействие солнца.

### Направляющая проводов у флага `#tpu95-10`

Направляющая является цельной сменной деталью с двумя закрытыми сквозными
каналами под провода Ø2 мм. Сервисный разрез запрещён: провода продеваются до
установки разъёма или подключения к клеммам. Ось направляющей расположена
примерно под 35° вниз к флагу, а её PETG-посадка находится на нижнем
скруглении `#petg-2`.

## 2. Вкладыш углепластиковой спицы

Файлы:

- `spoke_liner_A_split_face_down.stl`;
- `spoke_liner_B_split_face_down.stl`.

### Назначение

- распределяет усилие обжатия по длине спицы;
- исключает контакт углепластика с жёсткой кромкой PETG;
- уменьшает риск расслоения или смятия трубки;
- компенсирует небольшую погрешность диаметра.

### Почему он не выпадает

Каждая половина имеет:

1. увеличенный фланец на внутреннем конце;
2. увеличенный фланец возле выхода;
3. два гибких наружных ключа, которые входят в карманы соответствующей PETG-половины.

После соединения корпуса вкладыш физически заперт по всем направлениям.
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

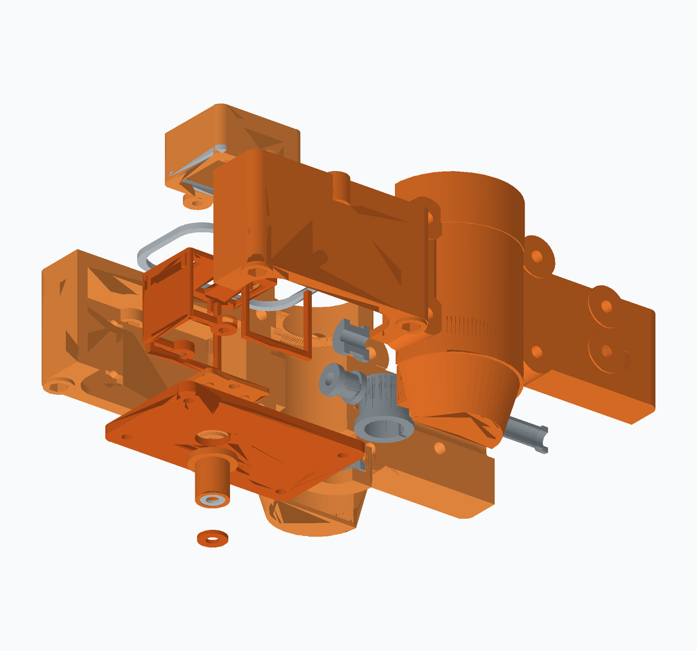
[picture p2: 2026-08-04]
mechanical/preview_v06_exploded_PETG_TPU.png

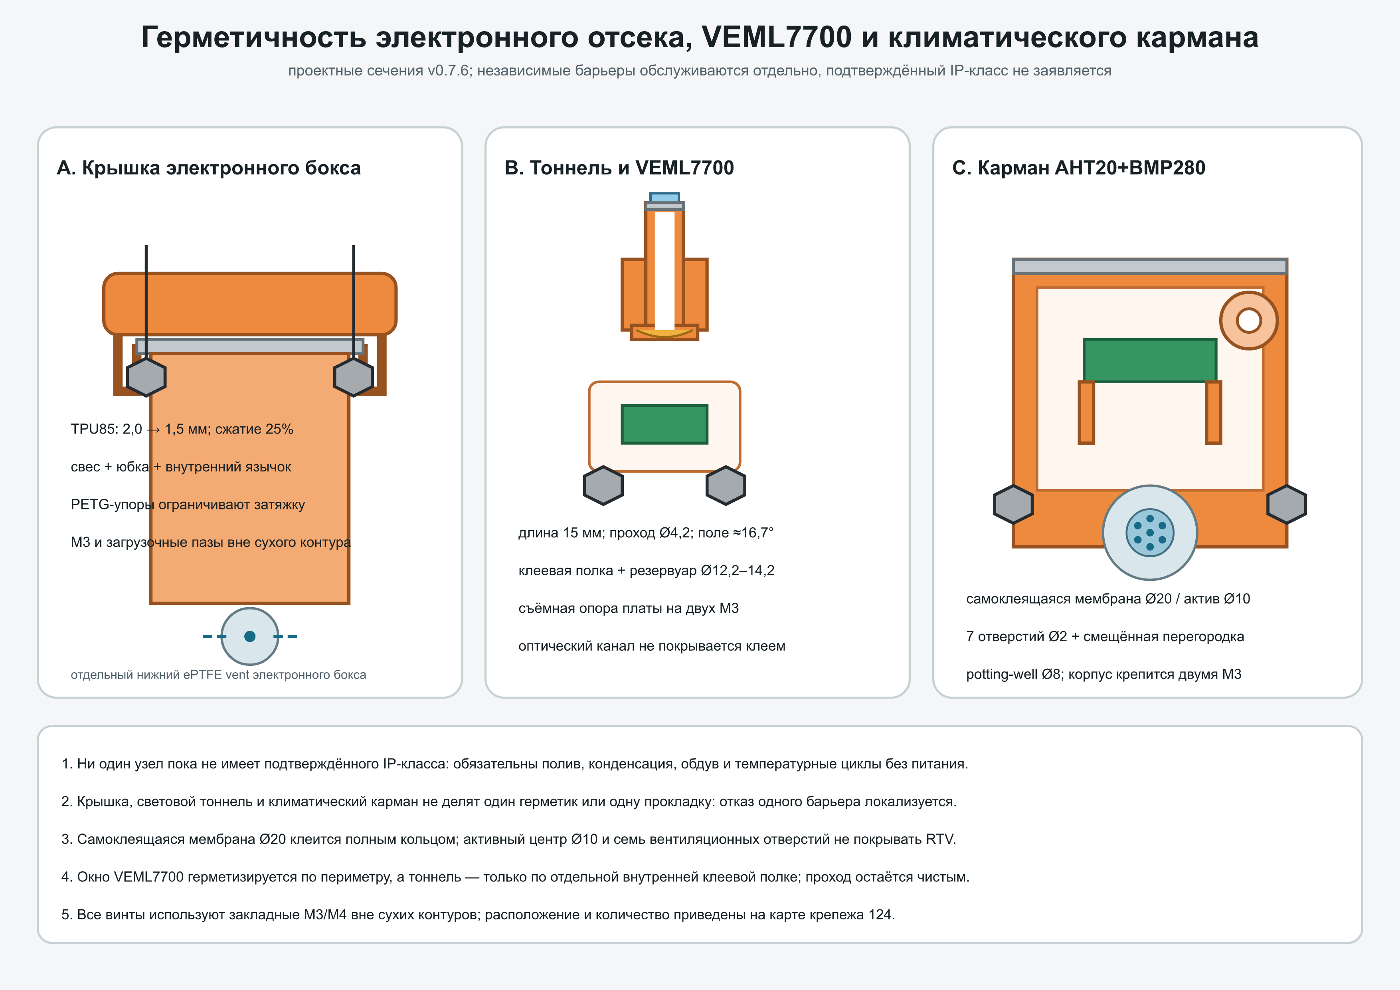
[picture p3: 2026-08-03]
mechanical/hermeticity_design_A4_landscape.png

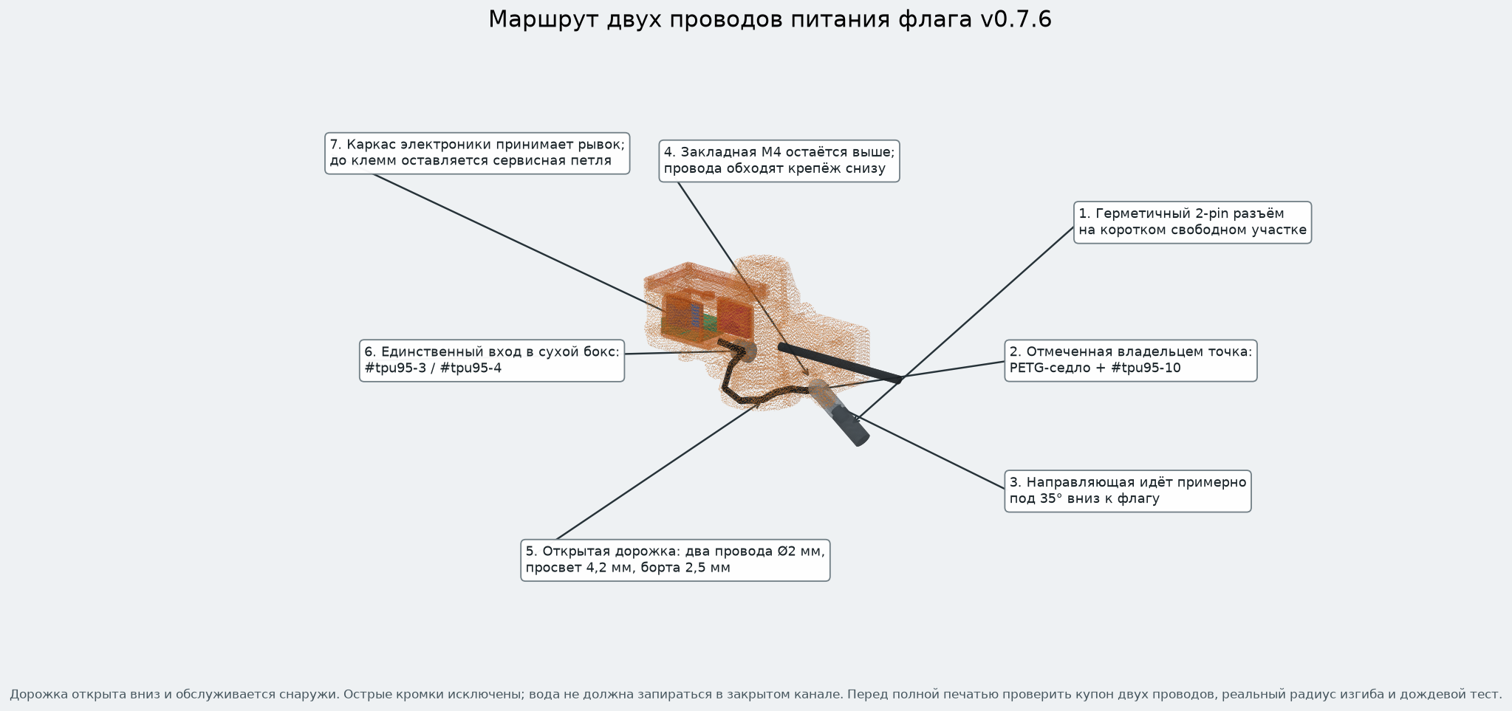
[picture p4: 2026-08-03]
mechanical/preview_v06_flag_power_route.png

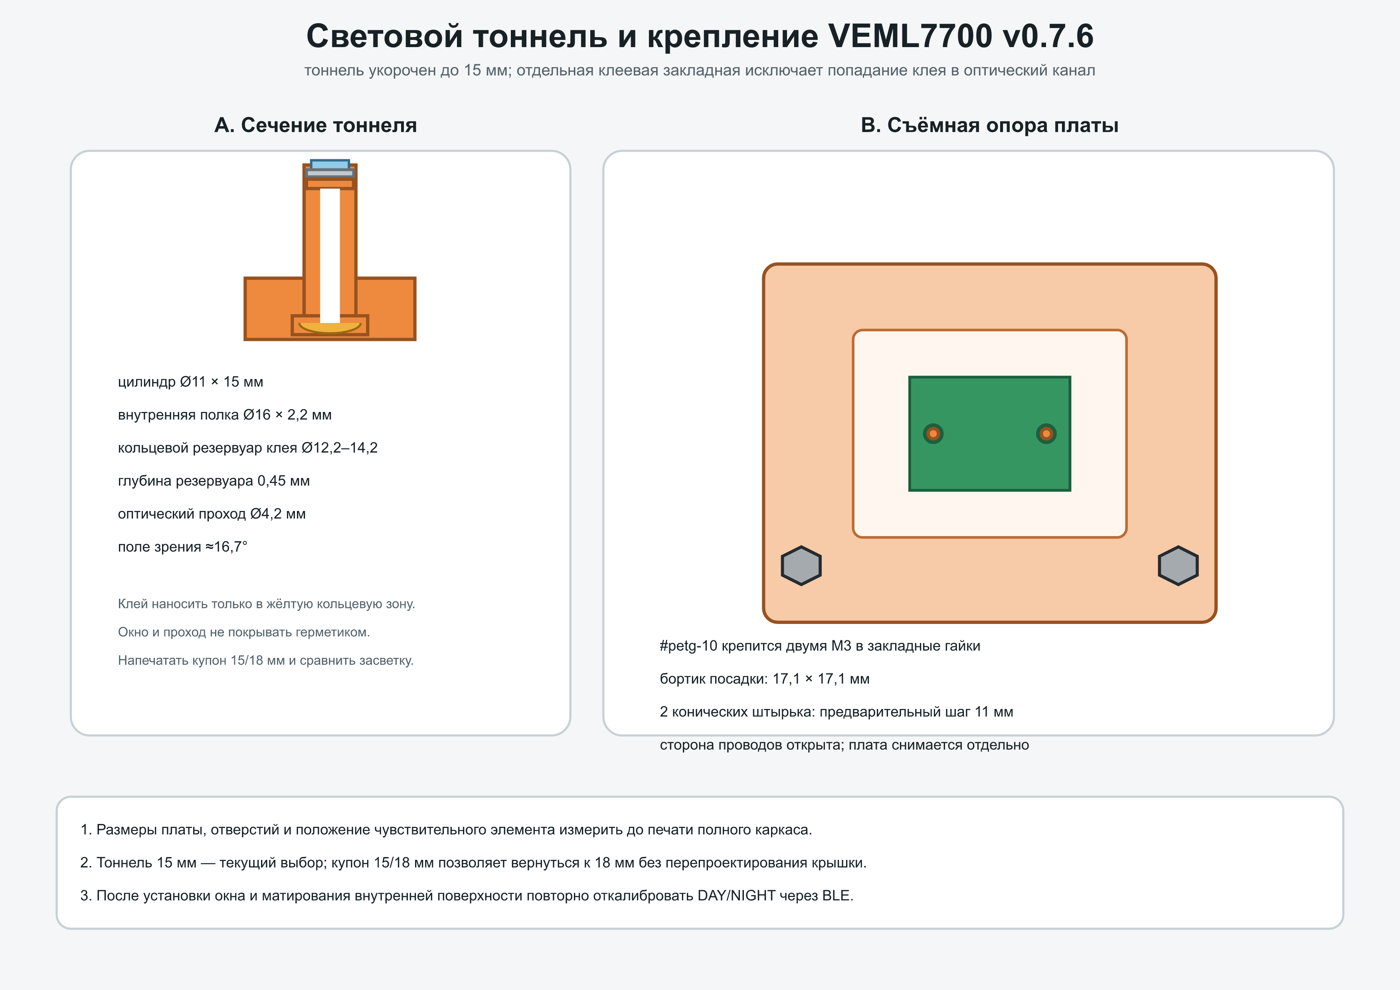
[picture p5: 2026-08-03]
mechanical/photo_tunnel_veml_mount_A4_landscape.png

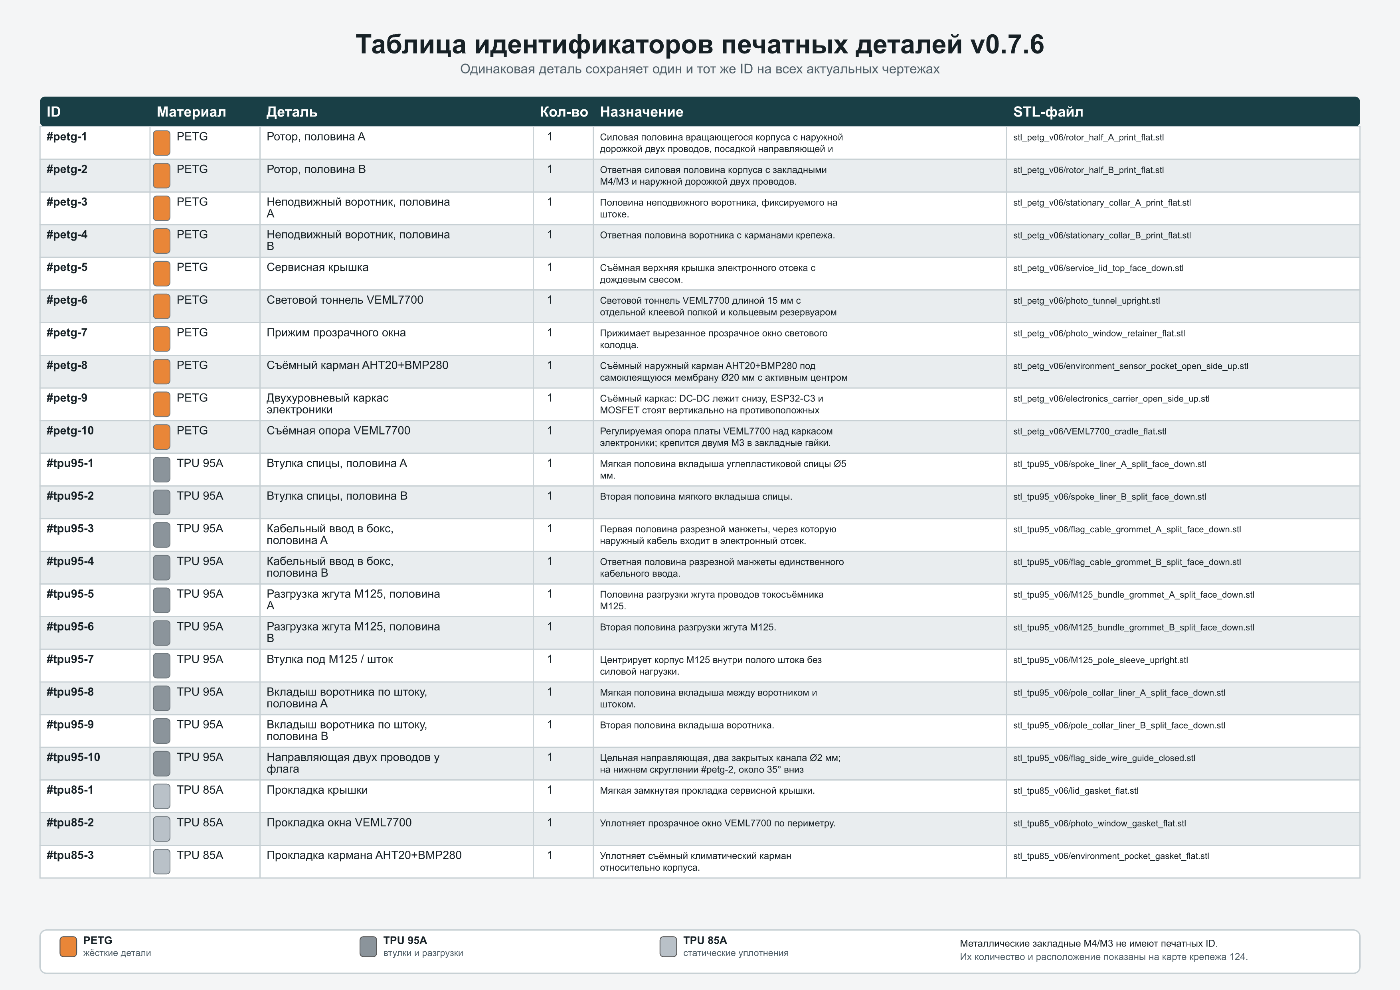
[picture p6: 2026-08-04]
mechanical/part_id_table_v06.png

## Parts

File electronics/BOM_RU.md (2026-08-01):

# Перечень электроники v0.7

## Основные модули

| Поз. | Компонент | В устройстве | Резерв |
| --- | --- | ---: | ---: |
| U1 | ESP32-C3 SuperMini Plus | 1 | 1 |
| U2 | VEML7700 I²C | 1 | 1 |
| U3 | AHT20+BMP280, комбинированный модуль | 1 | 1 |
| U4 | DC-DC 12→5 В | 1 | 1 |
| Q1 | LR7843 MOSFET-модуль | 1 | 1 |
| SR1 | Senring M125-0205, предпочтительно | 1 | — |
| LED1 | круглый светодиодный неон 12 В Ø16 мм | по контуру | запас |
| J1 | лёгкий герметичный отсоединяемый разъём к флагу | 1 пара | 1 пара |

## Питание

Внешняя подсистема:

```text
6 × 18650 → BMS/стабилизатор → 12 В на Crucian
```

BMS и зарядка находятся вне проекта навершия, но должны иметь собственную защиту и предохранитель.

Напряжение аккумулятора ESP не измеряет; делитель ADC не покупать для этой версии.

## Обвязка

- предохранитель по фактическому току ленты;
- электролит 1000–2200 мкФ / 25 В на входе 12 В;
- электролит 220–470 мкФ / 10–16 В возле ESP;
- керамические 100 нФ;
- резистор затвора 100 Ом;
- подтяжка затвора 100 кОм;
- силиконовый провод соответствующего сечения;
- четырёхжильный тонкий кабель к I²C-модулям;
- сервисный разъём питания ESP.

## MOSFET и PWM

Для плавной яркости PWM подаётся непосредственно на затвор LR7843 через 100 Ом, с подтяжкой 100 кОм к GND. Если используется готовая плата PC817+LR7843, сначала проверить её схему; PC817 допускается обойти прямой пайкой к затвору.

## Не входят

- измеритель напряжения аккумулятора;
- отдельный PWM-контроллер;
- светодиод глаза;
- EL-инвертор;
- облачный или Wi-Fi сервер.

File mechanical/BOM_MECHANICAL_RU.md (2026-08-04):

# Механический перечень v0.7.6

## Печатаемые детали

- 10 деталей PETG;
- 10 деталей TPU 95A;
- 3 прокладки TPU 85A;
- 17 тестовых купонов перед полной печатью.

Полный перечень и пути STL: `mechanical/part_id_registry_v06.json`.

## Металл и покупные узлы

- 2× выбранный закрытый подшипник 2RS — модель, размеры и статус покупки в карточке [#008](../catalog/catalog.html#component-008); прежний 6804-2RS не используется;
- 2× жёсткая переходная втулка PETG `#petg-11` между фактическим древком и внутренними кольцами новых подшипников — пока только заготовка [#401](docs/PETG_6806_BEARING_ADAPTER_RU.md), окончательные посадки после пробников;
- 1× закрытая нижняя втулка-разгрузка TPU 85A `#tpu85-4` между M125 и аккумулятором — пока только заготовка [#402](docs/LOWER_POLE_CABLE_STRAIN_RELIEF_RU.md), два канала под отдельные жилы Ø2 мм;
- углепластиковая спица Ø5 мм;
- токосъёмник M125-0205;
- 8× гайка M4 и соответствующие винты/шайбы;
- 10× гайка M3 и соответствующие винты/шайбы;
- 4× сменная уплотнительная шайба под головку M3 сервисной крышки: EPDM/силикон или металл-резиновая bonded seal; размер выбрать по фактическому винту;
- верхняя секция штока — измерения и расчётные значения только в карточке [#015](../catalog/catalog.html#component-015);
- герметичный 2-pin разъём возле флага.

Все гайки и посадки подтверждаются купонами. Количество крепежа следует покупать с запасом для испытаний.

Текущие центральные детали ротора и посадки под 6804 нельзя отправлять в печать до регенерации CAD. Новые пробники #40101–#40106 и #40201–#40206 пока существуют только в исходных заготовках и не считаются готовыми STL.

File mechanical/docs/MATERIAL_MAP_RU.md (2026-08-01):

# Карта материалов v0.7

## Текущий жёсткий материал: оранжевый PETG

Печатать из PETG каталоги `mechanical/stl_petg_v06/` и PETG-купоны.

PETG сейчас выбран не как абстрактно идеальный наружный пластик, а как реально купленный материал текущей сборки. Все посадки калибруются под конкретную катушку и Bambu Lab X1 Carbon.

## Будущая возможная замена: ASA

ASA не является текущим обязательным материалом. Когда появится бюджет, из ASA можно перепечатать наружные жёсткие детали. До этого необходимо повторить:

- купоны подшипника;
- закладные гаек;
- утончения под сверление;
- посадку крышки;
- проверку коробления половин корпуса.

## TPU 95A

Каталог:

```text
mechanical/stl_tpu95_v06/
```

Роли:

- вкладыш углепластиковой спицы;
- разрезная манжета единственного кабельного ввода у электронного бокса;
- разгрузка пучка M125;
- втулка M125;
- вкладыш воротника штока.

TPU95 держит форму и распределяет прижим, но не заменяет несущую PETG-геометрию.

## TPU 85A

Каталог:

```text
mechanical/stl_tpu85_v06/
```

Роли:

- прокладка сервисной крышки;
- прокладка прозрачного окна VEML7700;
- прокладка кармана AHT20+BMP280;
- прокладка гидрофобной мембраны.

TPU85 мягче и используется там, где важнее герметичное сжатие, чем удержание формы.

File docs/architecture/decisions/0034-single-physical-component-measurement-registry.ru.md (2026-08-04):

# ADR-0034: единый реестр физических размеров компонентов

- Статус: Принято
- Дата: 2026-08-04

## Контекст

Размеры покупных плат, древка, подшипников, мембраны, проводов и других физических компонентов повторялись в карточках, текущей документации и пояснениях 3D-моделей. После измерения реального древка старые значения остались в нескольких местах и могли привести к печати несовместимой геометрии.

Размеры печатных деталей имеют другую природу: они выводятся параметрическим CAD и не должны смешиваться с измерениями покупных объектов.

## Рассмотренные варианты

- оставить размеры в `components.json` и вручную повторять в документах — отклонено из-за расхождений;
- создать отдельный вручную заполняемый Markdown-каталог — отклонено как второй производный источник рядом с веб-страницей;
- хранить физические значения в одном структурированном JSON, объединять его с карточками при генерации сайта и ссылаться на стабильные якоря — принято.

## Решение

`catalog/physical-components.json` содержит ровно одну запись для каждого ID из `catalog/components.json`. Каждое значение имеет стабильный ключ, отображаемое значение, единицу, статус и источник. Допустимые статусы различают измерение, расчёт, стандарт, данные продавца, данные размерной фотографии и предварительное допущение.

`catalog/components.json` сохраняет назначение, варианты названия, электрические характеристики, ссылки и неразмерные пояснения. Физические размеры и масса там не дублируются.

Генератор объединяет два JSON по ID и создаёт стабильные адреса `catalog/catalog.html#component-<ID>`. Актуальные README, тематические документы и `catalog/media-descriptions/<ID>.md` ссылаются на конкретную карточку вместо копирования физического числа. §physicalcomponents1

Численные размеры печатных тел, отверстий, пазов и посадок остаются в параметрическом CAD и его машинном отчёте. Исторические ADR и отчёты могут сохранять значения времени принятия решения, если их исторический статус очевиден.

## Последствия

- новый замер редактируется один раз и автоматически появляется на сайте;
- модельные описания имеют точные ссылки на исходные физические данные;
- вычисленные значения, например овальность, явно отделены от прямых измерений;
- изменение размера компонента не означает автоматическую регенерацию CAD: сначала оценивается влияние, затем по отдельному решению обновляются модели;
- пустая запись допустима и показывает, какие размеры ещё нужны.

## Проверка

- генератор требует полного совпадения ID двух JSON;
- якорь обязан иметь формат `component-<ID>`;
- ключи измерений внутри карточки уникальны;
- статус и источник каждого значения обязательны;
- `npm.cmd run catalog:check` проверяет JSON и синхронизацию HTML;
- тесты проверяют наличие постоянной ссылки и вывод размеров для каждой карточки.

## Когда пересматривать

- если физические измерения станут напрямую импортироваться из системы метрологии;
- если CAD начнёт читать численные интерфейсные параметры из отдельной строго типизированной схемы;
- если один component-ID начнёт описывать несколько фактически разных экземпляров с независимыми картами измерений.

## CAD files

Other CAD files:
mechanical/build123d_v076/tpu95-8_pole_collar_liner_A.step
mechanical/stl_petg_v06/environment_sensor_pocket_open_side_up.stl
mechanical/stl_tpu85_v06/photo_window_gasket_flat.stl
mechanical/stl_tpu95_v06/M125_bundle_grommet_A_split_face_down.stl
mechanical/test_coupons_v06/TPU95_M125_sleeve_OD_16.00.stl
mechanical/build123d_v076/tpu95-6_M125_bundle_grommet_B.step
mechanical/stl_petg_v06/photo_window_retainer_flat.stl
mechanical/stl_tpu85_v06/lid_gasket_flat.stl
mechanical/stl_tpu95_v06/spoke_liner_A_split_face_down.stl
mechanical/test_coupons_v06/bearing_seat_32.50_half_B.stl
mechanical/build123d_v076/petg-8_environment_sensor_pocket.step
mechanical/stl_petg_v06/photo_tunnel_upright.stl
mechanical/stl_tpu85_v06/environment_pocket_gasket_flat.stl
mechanical/stl_tpu95_v06/flag_cable_grommet_B_split_face_down.stl
mechanical/build123d_v076/tpu95-3_flag_cable_grommet_A.step
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

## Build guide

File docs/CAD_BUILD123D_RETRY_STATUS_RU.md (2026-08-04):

# Статус повторной попытки полной CAD-линии build123d

Дата среза: 2026-08-04.

## Цель проверки

Исходное задание требует сохранить каноническую SDF/trimesh-линию и параллельно построить экспериментальную линию для всех 23 печатных деталей по цепочке:

```text
Python/build123d → STEP/B-Rep → STL/GLB → чертежи и сравнение → третья вкладка каталога
```

До решения владельца эксперимент не заменяет старые файлы, не используется для изготовления и не объединяется с основной веткой.

## Что подтверждено повторно

1. Исходный снимок рабочего дерева проверен по 411 внутренним SHA-256 без расхождений.
2. Канонический `mechanical/generate_models_v06.py` выполнен в отдельной полной копии дерева с кодом 0.
3. Сравнены 40 STL, 7 GLB и 2 JSON-отчёта: **49/49 эквивалентны**. Полный протокол находится в:
   - `docs/LEGACY_CAD_REGENERATION_AUDIT_RU.md`;
   - `mechanical/LEGACY_REGENERATION_AUDIT_V076.json`.
4. Основное рабочее дерево при повторной генерации не перезаписывалось.
5. Commit, push, merge и PR не выполнялись.

## Что было проверено в исходной изолированной среде

Фактическая среда:

- Python 3.13.5;
- модуль `build123d` отсутствует;
- модуль `OCP` отсутствует;
- FreeCAD и OpenSCAD отсутствуют;
- настроенный в среде индекс `pip` не содержит `build123d`, `cadquery-ocp-novtk` или `cadquery-ocp`;
- прямое получение бинарного колеса OpenCascade из внешнего хранилища в этой среде завершилось ошибкой загрузки/разрешения имени.

Эти сведения описывают прежнюю Linux-среду подготовки архива и больше не
являются текущим состоянием Windows-компьютера владельца.

## Что установлено на Windows 2026-08-04

- FreeCAD 1.1.3 через `winget install --id FreeCAD.FreeCAD --exact` в стандартную пользовательскую папку Windows;
- OpenSCAD 2021.01 через `winget install --id OpenSCAD.OpenSCAD --exact` в стандартную папку Windows;
- отдельная Python 3.12-среда `%USERPROFILE%\Documents\pesochnica\flagpole\.venv-build123d`;
- build123d 0.11.1;
- `cadquery-ocp-novtk` 7.9.3.1.1, предоставляющий импорт `OCP`.

Импорты `build123d` и `OCP` успешно проверены. Воспроизводимый установщик —
`tools/windows/setup-cad.ps1`; общий `tools/windows/setup.ps1 -Install` также
вызывает его.

## Граница результата

Построен первый честно ограниченный пилот:

- #petg-5, #petg-6 и #petg-10 имеют native build123d/OCP STEP и STL;
- гибридный GLB #211 содержит эти три B-Rep-пилота и двадцать канонических сеток;
- отдельная вкладка «Новый CAD» изолирует эксперимент от текущей #204;
- JSON-отчёт фиксирует 23 узла, три native-узла и двадцать legacy-узлов.

По-прежнему **не создавались и не выдаются за готовые** полные 23 STEP/B-Rep,
полные экспериментальные производственные STL, численное сравнение всех тел и
утверждение полной миграции.

Создание фиктивных STEP, переименование STL старой линии или выдача упрощённых схем за B-Rep запрещены. Это сохранило честную границу доказательства, но означает, что исходный критерий полной параллельной CAD-линии пока не выполнен.

## Как повторить установку

Минимальный порядок:

```powershell
powershell -ExecutionPolicy Bypass -File tools\windows\setup-cad.ps1 -Install
```

Продолжать нужно строго по `mechanical/docs/BUILD123D_MCP_WORKFLOW_RU.md`: сначала сравнить три пилота, затем после решения владельца переносить остальные двадцать деталей. Старый CAD остаётся каноническим до отдельного выбора владельца.

## Граница текущего кумулятивного пакета

Пакет содержит:

- полностью проверенное исходное дерево со всеми прежними незапушенными изменениями;
- новый слой подробных описаний всех 30 медиа-ID;
- повторную проверку воспроизводимости старой CAD-линии;
- этот точный статус и инструкции продолжения.

Пакет не заявляет завершение build123d-миграции и не содержит подмены старых моделей экспериментальными.

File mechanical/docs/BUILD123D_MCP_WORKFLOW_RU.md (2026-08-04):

# CAD-процесс build123d для Super_pommels_and_flag

<!-- §cadworkflow -->

## Решение

В проект добавляется только один внешний CAD-инструмент: `pzfreo/build123d-mcp` с тремя его процессными навыками:

- `modeling` — пошаговое построение и измерение B-Rep-геометрии;
- `drawing` — получение основных видов, сечений и размеров;
- `repair` — локализация и исправление невалидных операций/тел.

`text-to-cad`, `draftwright` и `blender-industrial-kit` не становятся обязательными зависимостями. Первый дублирует уже существующие правила репозитория, второй имеет смысл только после появления устойчивых STEP, третий относится к Blender-визуализации, а не к производственному источнику геометрии.

## Подключение MCP

Локальный сервер запускается агентом как подпроцесс:

```text
command: uv
args: ["tool", "run", "--python", "3.12", "build123d-mcp@latest"]
```

После подключения доступны процессные инструкции:

```text
install_skill(target="agents-md", skill="modeling")
install_skill(target="agents-md", skill="drawing")
install_skill(target="agents-md", skill="repair")
```

Их полный автоматически сгенерированный текст не копируется в корневой `AGENTS.md`: проектные правила ID, каталога, версий и публикации уже закреплены там и остаются единственным источником истины.

## Иерархия источников

Для новой CAD-детали действует цепочка:

```text
build123d Python source → STEP → STL/GLB → чертежи/превью → каталог
```

Редактируется Python-источник. STEP — основной обменный B-Rep-артефакт, но не самостоятельный ручной источник. STL, GLB, PDF, SVG и DXF являются производными файлами.

Если владелец просит подготовить деталь без генерации, промежуточная цепочка выглядит так:

```text
единый JSON размеров → opt-in build123d Python source → HTML-карточка source-only
```

STEP/STL/GLB/PNG при этом отсутствуют. Примеры — заготовка [#401](PETG_6806_BEARING_ADAPTER_RU.md)
жёсткой PETG-втулки и [#402](LOWER_POLE_CABLE_STRAIN_RELIEF_RU.md) гибкой
TPU85-разгрузки; их JSON является источником и для сайта, и для будущей
генерации. §bearingadapter1 §lowercablestrain1

## Граница миграции

Новый CAD-контур охватывает только 23 канонические печатные детали PETG/TPU,
их STEP/STL, печатные раскладки и основную разнесённую модель печатного
комплекта #204.

Следующие материалы остаются на прежних генераторах и обновляются только по
прямому запросу владельца: схема соединений электроники, выкройка четырёх
лямок, общий вид сборки, маршрут проводов, продольная схема, отдельный лист
светового тоннеля/VEML7700, компоновка электроники, шаблон рыбы, а также
интерактивные общий вид и компоновка электроники. Они могут ссылаться на
параметры печатной механики, но не становятся build123d-артефактами. При
обычной регенерации нового CAD запрещено запускать их старые генераторы или
менять их производные SVG/PNG/GLB без отдельной команды владельца.

`mechanical/generate_build123d_canonical_v076.py` является источником всех 23 печатных деталей и модели #204. `mechanical/generate_models_v06.py` сохраняется только для старых справочных сцен и вызывается отдельным режимом `legacy-references` по прямому запросу владельца. Переход на B-Rep не объявляет существующие посадки физически подтверждёнными.

Заготовки #401/#402 не увеличивают число канонических деталей: будущие
`#petg-11` и `#tpu85-4` добавляются в основную линию только после печати
независимых пробников, утверждения размеров и разрешённой генерации.

## Пилот миграции

Перенос начинается только с трёх ограниченных деталей:

1. `#petg-6` — световой тоннель: цилиндры, клеевая полка, окно и сечение;
2. `#petg-10` — опора VEML7700: отверстия, межосевые размеры и M3;
3. `#petg-5` — сервисная крышка: сопряжение, паз TPU и сборочное сечение.

Половины ротора переносятся только после того, как эти три пилота проходят проверки и не требуют ручной правки производных файлов.

## Обязательный цикл

1. Построить одну операцию.
2. Отрендерить или измерить результат.
3. Проверить критические размеры и именованные зазоры.
4. Выполнить `validate()`.
5. Экспортировать STEP.
6. Получить STL из того же тела.
7. Сравнить габариты и объём с текущим артефактом.
8. Сформировать основные виды и обязательные сечения.
9. Выполнить проектный quality gate.

## Критерии принятия пилотной детали

- тело валидно и замкнуто;
- STEP воспроизводимо строится из Python;
- один стабильный ID используется в исходнике, имени STEP-тела, STL, чертеже и каталоге;
- измерены габариты, отверстия, глубины пазов, стенки и посадочные зазоры;
- чертёж содержит изометрию, спереди, сверху, сбоку и требуемое сечение;
- STEP/STL/PDF/SVG/DXF не исправлялись вручную после генерации;
- физически непроверенные размеры по-прежнему помечены как предварительные.

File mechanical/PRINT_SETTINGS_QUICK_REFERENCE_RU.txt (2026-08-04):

BAMBU LAB X1 CARBON, СОПЛО 0,4 ММ

ТЕКУЩАЯ СБОРКА — ОРАНЖЕВЫЙ PETG
- сопло 240–245 °C
- стол 75–85 °C
- слой 0,20 мм
- корпус: 7 стенок, 6 верх/низ, 40% Gyroid
- внешняя стенка 35–45 мм/с
- обдув 0% первые 3 слоя, затем 20–30%
- Aux Fan минимум/выключен
- половины корпуса плоскостью разъёма вниз
- brim 8–12 мм

TPU 95A
- сопло около 225 °C
- стол около 45 °C
- 18–25 мм/с
- 4 стенки, 100% заполнение
- минимальный ретракт
- внешняя катушка, не стандартный AMS-тракт

TPU 85A
- сопло 220–230 °C
- стол 35–45 °C
- 12–20 мм/с
- 4 стенки, 100% заполнение
- минимальные ускорение и ретракт

СНАЧАЛА КУПОНЫ
1. ПОДШИПНИКОВЫЙ КУПОН: пока не печатать — старый 6804 отклонён; выбранный подшипник и древко см. в карточках #008 и #015 физического каталога
2. M125: 15,60 / 15,80 / 16,00
3. закладная M4
4. утончения 0,6 / 0,8 / 1,0
5. PETG-паз + TPU85-прокладка

ASA — ТОЛЬКО БУДУЩАЯ ЗАМЕНА
После покупки ASA повторить все купоны; PETG-посадки автоматически не переносить.
РАСКЛАДКИ И ПОДЛОЖКИ
- PETG/TPU95/TPU85 печатаются отдельными очередями
- канонических PETG-подложек под TPU нет
- #petg-5 — функциональная крышка, не raft
- brim/raft задаётся только в слайсере
- автоматический зазор: PETG 6 мм, TPU 5 мм

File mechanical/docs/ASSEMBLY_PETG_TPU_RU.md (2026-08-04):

# Сборка механики v0.7.6: PETG + TPU 95A + TPU 85A

## 1. До полноразмерной печати

Обязательно:

1. измерить детали по `MEASUREMENTS_REQUIRED_RU.md`;
2. прочитать `docs/MECHANICAL_FITS_RU.md`;
3. напечатать купоны подшипников, M125, гайки, утончения, дорожку двух проводов и крепление VEML7700;
4. перенести выбранные значения в `mechanical/generate_build123d_canonical_v076.py`;
5. повторно сгенерировать STEP/STL/GLB штатным build123d-контуром;
6. проверить `mechanical/VALIDATION_REPORT_V06_RU.md`.

## 2. Закладные гайки

Перед соединением половин:

- вставить M4 в карманы ответной половины корпуса;
- M3 крышки и крепления `#petg-8` опустить сверху в глухие колодцы после снятия этих деталей; остальные M3 установить через предусмотренные обслуживаемые входы;
- четыре колодца сервисной крышки находятся внутри бокса, имеют наружный диаметр 10 мм и длину 18 мм; не сверлить их насквозь и не пытаться вставлять гайки со стороны наружной стенки;
- прокладка должна образовывать непрерывный замкнутый сухой контур внутри линии четырёх винтов; винтовые отверстия остаются во внешней мокрой зоне, разрезать прокладку возле них нельзя;
- под головки четырёх M3-винтов крышки установить сменные EPDM/силиконовые либо металл-резиновые уплотнительные шайбы; они являются вторичным барьером и не заменяют внутреннюю TPU85-прокладку;
- проверить, что удерживающий вход не треснул;
- убедиться, что гайка не выступает в плоскость разъёма;
- при необходимости применить одну точку нейтрального RTV, но не заливать карман полностью.

После закрытия узла гайка должна быть механически заперта второй деталью.
Наружных боковых загрузочных отверстий у гаек крышки и `#petg-8` быть не должно.

## 3. TPU 95A

### Спица

Вкладыш удерживается фланцами и ключами. Клей не должен попадать в канал Ø5 мм.

### Кабель к флагу

Два провода питания Ø2 мм проходят **снаружи корпуса ниже гайки между PETG-бортами с просветом 4,2 мм и высотой 2,5 мм**. Он входит в герметичный электронный отсек только один раз — через разрезную TPU 95A-манжету непосредственно около электронного бокса.

Возле флага провода проходят через сменную направляющую `#tpu95-10`, которая
садится в глухое гнездо `#petg-2_ввод_флага` и не пробивает стенку ротора. Затем
остаётся короткий пигтейл с герметичным разъёмом. Внутри бокса оставляется
сервисная петля до клеммы/MOSFET.

Подробно: `mechanical/docs/FLAG_POWER_CABLE_ROUTE_RU.md`.

### M125

Корпус токосъёмника центрируется TPU-втулкой и не несёт массу навершия.

## 4. TPU 85A

Прокладки устанавливать сухими в штатные пазы. Допустимы редкие точки нейтрального RTV только для удержания при обслуживании.

Не заменять механический паз сплошным слоем силикона.

Будущая нижняя разгрузка `#tpu85-4` пока не входит в печатную очередь. После
проверки свободной глубины стыка сначала подобрать шесть рёбер пробниками #40201–#40203, затем
проверить два канала под жилы Ø2 мм пробниками #40204–#40206. Жилы продеваются
до установки разъёма, над втулкой остаётся свободный запас, а разъединённую
секцию нельзя подвешивать на проводе. §lowercablestrain1

## 5. Карман AHT20+BMP280

- PETG-карман съёмный;
- плата ориентируется чувствительной кромкой к мембране;
- отверстия сверлятся после печати по утончённым площадкам;
- прямого продува насквозь быть не должно;
- кабельный проход в электронный отсек сверлится после примерки и герметизируется;
- сам датчик не покрывается лаком или компаундом.
- самоклеящаяся мембрана Ø20 мм с активным центром Ø10 мм ставится изнутри;
- семь отверстий Ø2 мм сверлятся после печати через утончения и остаются внутри активной зоны;
- четырёхпроводный жгут проходит через отдельный potting-well Ø8 мм;
- герметик заполняет только колодец проводов, а не камеру датчика.

## 6. Световой тоннель, окно и VEML7700

Порядок:

1. примерить купон крепления реальной платы VEML7700;
2. установить плату на четыре опоры и два конических штырька без напряжения;
3. вставить тоннель Ø11 × 18 мм изнутри наружу;
4. вклеить непрерывным тонким кольцом возле внутренней шайбы Ø16 × 2,2 мм;
5. вырезать прозрачное окно по фактической заготовке;
6. установить `#tpu85-2`, окно и `#petg-7`;
7. не допускать силикона в оптический проход и на чувствительный элемент;
8. после окончательной сборки откалибровать DAY/NIGHT через BLE.

См. `mechanical/docs/PHOTO_TUNNEL_AND_VEML_MOUNT_RU.md`.

## 7. Подшипники и спица

- подшипники устанавливаются без молотка;
- половины затягиваются постепенно крест-накрест;
- после каждого шага проверяется свободное вращение;
- спица заканчивается до центральной оси;
- TPU-вкладыш не должен полностью выдавливаться из зажима.

## 8. Тканевые лямки

Четыре лямки пришиваются к левому усиленному краю флага. Они не входят в печатную механику, но являются обязательной частью сборки флага.

См. `mechanical/docs/FLAG_ATTACHMENT_LOOPS_RU.md`.

## 9. Дождевой тест

До питания:

- сухая бумага в электронном отсеке;
- полив сверху и со всех сторон 20 минут;
- медленное вращение;
- выдержка минимум 2 часа;
- проверка окна, мембраны, дренажа, кабельного выхода, M125 и подшипников.

## 10. Что стало с дополнительным отверстием возле спицы

В предыдущей компоновке рядом со спицей было отдельное отверстие для кабеля. После уточнения маршрута оно **исключено из актуальной концепции**.

Теперь:

- кабель идёт под спицей по внешней открытой канавке;
- силовая зона крепления спицы не имеет второго прохода;
- в корпус кабель входит только возле электронного бокса;
- место ввода уплотняется деталями `#tpu95-3` и `#tpu95-4`.

Поэтому на новой механике отверстие чуть выше спицы не требуется. Если оно видно на исторической картинке v0.5, это устаревший вариант.

## 11. ID деталей на актуальных чертежах

На разнесённый вид v0.7.6 и на отдельные раскладки PETG / TPU 95A / TPU 85A нанесены стабильные ID деталей.

См.:

- `mechanical/docs/PART_IDENTIFIERS_RU.md`;
- `mechanical/part_id_registry_v06.json`.

## 12. Крышка электронного бокса

- бокс вынесен наружу от оси древка: центр отсека находится на `X = −60 мм`, поэтому крышка не заходит под центральную башню ротора;
- прямоугольная крышка 74 × 44 мм соответствует прямоугольной ответной рамке бокса 72 × 42 мм;
- перед окончательной сборкой проверить, что внутренний направляющий бурт крышки свободно входит в проём, не упирается в стенку и не защемляет провод;
- уложить `#tpu85-1` в замкнутый паз;
- проверить непрерывный отпечаток прокладки по периметру;
- затягивать винты крест-накрест до контакта жёстких PETG-упоров;
- не использовать винты для дополнительного смятия прокладки;
- проверить, что наружный свес, юбка и внутренний язычок не повреждены;
- установить отдельную нижнюю vent-мембрану и не покрывать её активную область герметиком.

В цифровой модели проверяются совпадение контуров, зазор крышки относительно башни и отсутствие объёмного пересечения. Это не подтверждает IP-рейтинг: после печати выполнить пробу отпечатка прокладки и дождевой тест без установленной электроники.

См. `mechanical/docs/HERMETICITY_V074_RU.md`.

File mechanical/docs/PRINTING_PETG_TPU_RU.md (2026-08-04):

# Печать v0.7.6 на Bambu Lab X1 Carbon, сопло 0,4 мм

## 1. Материалы этой версии

```text
жёсткие детали сейчас:  оранжевый PETG
функциональные мягкие:  TPU 95A
статические прокладки:  TPU 85A
будущая замена PETG:    ASA, только после повторных купонов
```

Не переносить температуры и посадочные компенсации PETG на ASA.

## 2. Обязательный порядок

1. Высушить катушку.
2. Создать отдельный профиль каждой катушки в Bambu Studio.
3. Откалибровать flow ratio и pressure advance.
4. Напечатать купоны.
5. Измерить их после полного остывания.
6. Подставить выбранные значения в `generate_build123d_canonical_v076.py`.
7. Перегенерировать STL.
8. Только затем печатать корпус.

## 3. Оранжевый PETG

Стартовый профиль, который затем уточняется под производителя:

```text
сопло:                   240–245 °C
стол:                    75–85 °C
слой:                    0,20 мм
первый слой:             0,22–0,24 мм
внешняя линия:           0,42–0,45 мм
внутренняя линия:        0,45–0,48 мм
```

### Прочность корпуса

```text
стенки:                  7
верх/низ:                6 слоёв
заполнение:              40% Gyroid
внешняя стенка:          35–45 мм/с
внутренняя стенка:       55–70 мм/с
первый слой:             18–25 мм/с
```

Не использовать предельную скорость X1 Carbon для несущих деталей. Межслойное сплавление важнее времени печати.

### Обдув

```text
первые 3 слоя:           0%
обычная печать:          20–30%
короткие мосты:          до 45–55%
Aux Fan:                 выключен или минимум
```

### Прилипание

- половины корпуса: brim 8–12 мм;
- крышка: 4–6 мм;
- воротник: 3–5 мм;
- световой тоннель: 3–4 мм.

На гладкой пластине использовать разделительный слой, если PETG слишком сильно сцепляется с поверхностью.

### Ориентация

- половины корпуса — плоскостью разъёма на стол;
- половины воротника — плоскостью разъёма вниз;
- крышка — внешней верхней поверхностью вниз;
- световой тоннель — вертикально;
- карман AHT20+BMP280 — открытой стороной вверх;
- кольцо окна — плоско.

Поддержки внутри посадок, карманов гаек и каналов запрещены.

## 4. TPU 95A

Используется для деталей, которые должны держать форму под прижимом.

```text
сопло:                   220–230 °C, начать 225 °C
стол:                    40–50 °C, начать 45 °C
слой:                    0,20 мм
скорость стенок:         18–25 мм/с
малые элементы:          15–20 мм/с
стенки:                  4
заполнение:              100%
обдув после 2-го слоя:   30–50%
ретракт:                 минимальный
```

TPU печатать с внешней катушки, без попытки проталкивать мягкий материал через стандартный AMS-тракт.

Ориентация:

- разрезные половины — плоскостью разъёма вниз;
- втулка M125 — вертикально;
- поддержки выключены.

## 5. TPU 85A

TPU 85A мягче и сильнее реагирует на подачу и ретракт. Начальный профиль:

```text
сопло:                   220–230 °C
стол:                    35–45 °C
слой:                    0,20 мм
скорость:                12–20 мм/с
стенки:                  4
заполнение:              100%
ретракт:                 минимально возможный
ускорение:               ниже, чем для TPU95
```

Печатать по одной или небольшой группой:

- прокладка крышки;
- прокладка окна;
- прокладка кармана;

После печати дать детали полежать без нагрузки и проверить восстановление после 24 часов пробного сжатия.

## 6. Купоны

Сначала печатать:

1. подшипники 32,20 / 32,35 / 32,50 мм;
2. M125 15,60 / 15,80 / 16,00 мм;
3. закладную M4;
4. утончения 0,6 / 0,8 / 1,0 мм;
5. PETG-паз + TPU85-прокладку крышки;
6. пробные прокладки окна и климатического кармана;
7. дорожку двух проводов 4,2 × 2,5 мм;
8. крепление платы VEML7700.

## 7. Закладные гайки

Карманы нельзя исправлять глобальным масштабированием модели. Изменять только параметры:

```text
m4_nut_pocket_across_flats
m4_nut_snap_entry_across_flats
m3_nut_pocket_across_flats
m3_nut_snap_entry_across_flats
```

## 8. Переход на ASA позднее

Когда будет куплена ASA:

1. использовать закрытый корпус X1 Carbon и безопасную вентиляцию помещения;
2. создать отдельный профиль;
3. повторить все PETG-купоны;
4. проверить коробление длинных половин;
5. не считать прежний PETG fit подтверждением ASA fit.

## 9. После печати

- не запрессовывать подшипники ударами;
- убрать только заусенцы;
- проверить гайки до окончательной сборки;
- собрать половины с шайбами и умеренным моментом;
- проверить вращение после каждого шага затяжки;
- выполнить дождевой тест без питания.

## 10. Раздельные очереди печати

Для текущего проекта за один запуск печатается только **один основной пластик**.

Правило:

- очередь 1 — PETG;
- очередь 2 — TPU 95A;
- очередь 3 — TPU 85A.

Не смешивать PETG, TPU 95A и TPU 85A в одной печати только ради экономии времени: на Bambu Lab X1 Carbon это приводит к лишним сливам материала и усложняет контроль качества.

В текущей версии **канонических PETG-подложек под TPU нет**:

- `#petg-5` — функциональная сервисная крышка сборки, а не жертвенная подложка;
- TPU-прокладки печатаются отдельно и затем устанавливаются в PETG-пазы;
- brim, raft и иные средства адгезии создаются настройками слайсера и не получают отдельный ID/STL/GLB;
- добавлять в раскладку фиктивную PETG-пластину запрещено: её можно ошибочно принять за часть изделия.

### Автоматическая компактная раскладка

`mechanical/layout_packing.py` размещает уже ориентированные детали по их реальным AABB на столе 256 × 256 мм. Сохраняется резерв 8 мм от края; минимальный зазор составляет 6 мм для PETG и 5 мм для TPU. Если комплект перестал помещаться, генерация завершается ошибкой вместо скрытого наложения деталей.

## 11. Цвет отображения белых деталей на рендерах

Белые или очень светлые детали на новых рендерах умышленно показаны **сероватыми**. Это сделано только для читаемости изображений: на светлом фоне чисто белые TPU-детали и прокладки почти пропадают.

На реальные материалы это правило не накладывает ограничений: серый цвет в рендерах не означает, что деталь должна быть напечатана серым пластиком.

## 12. Чертежи с ID и отдельные картинки по материалам

На сайт каталога добавлены:

- изображения раскладки PETG;
- изображения раскладки TPU 95A;
- изображения раскладки TPU 85A;
- карточки «Раздельные очереди печати по материалам» после блока интерактивных 3D-моделей.

Это нужно, чтобы следующий человек сразу видел, какой комплект печатать в какой запуск.

## 13. Параметрический источник v0.7.6

Все current-печатные детали строятся
`mechanical/generate_build123d_canonical_v076.py`. Старый
`generate_models_v06.py` обслуживает только справочные сцены и запускается по
отдельному запросу. После изменения параметров печатной механики требуется
регенерация STEP/STL, #204, печатных раскладок, целевых preview и validation
report; старые справочные SVG/PNG/GLB автоматически не трогать.

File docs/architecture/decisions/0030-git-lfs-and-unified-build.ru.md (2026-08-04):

# ADR-0030: Git LFS и единый сборочный интерфейс

- Статус: Принято
- Дата: 2026-08-03

## Контекст

STL и GLB занимают основную часть рабочего дерева и меняются как цельные бинарные файлы. Одновременно ручная регенерация требовала помнить порядок нескольких Python- и npm-команд. Без ограничения LFS-загрузок каждый CI job мог бы повторно скачивать сотни мегабайт и расходовать месячный трафик владельца.

## Рассмотренные варианты

- оставить все бинарные файлы в обычном Git — отклонено из-за роста будущей истории;
- перенести в LFS также все PNG — отклонено: PNG занимают заметно меньше места и нужны документации и каталогу;
- переписать всю опубликованную историю — отложено как рискованная необратимая операция;
- хранить в LFS все STL/GLB текущего и будущих коммитов, оставить PNG в Git и загружать LFS только в условной механической задаче — принято.

## Решение

`.gitattributes` направляет `*.stl` и `*.glb` в Git LFS. PNG остаются обычными Git-объектами. Миграция применяется новым коммитом без переписывания прежних опубликованных коммитов.

Единым интерфейсом регенерации является `scripts/build.mjs`; Windows запускает его через `build.cmd` или `tools/windows/build.ps1` только из защищённой копии под `FLAGPOLE_EXECUTION_ROOT`. Режимы: `all`, `generate`, `validate`, `catalog`, `ci`.

CI сначала выполняет проверки без загрузки LFS и классифицирует изменённые пути. Только условная задача механики выполняет один `git lfs pull --include="*.glb,*.stl"`. Android и обе прошивки работают с LFS-указателями и не скачивают модели. Проверка SHA-256 и генератор каталога читают исходный hash/size непосредственно из LFS-указателя.

Повторный экспорт STEP/STL/GLB через OCP и рендер PNG не обязаны быть побайтово одинаковыми между Windows и Linux: служебные поля, порядок записи и растеризация могут отличаться при той же геометрии. Производный JSON-отчёт содержит SHA этих GLB, а HTML-каталог — размеры производных превью, поэтому они также проверяются семантически, а не побайтово. Механический CI проверяет все 40 STL на замкнутость, ориентацию и единственный связный объём, выполняет семантические тесты модели и требует побайтового совпадения только от действительно детерминированных identity-файлов и индекса медиа-описаний. `CHECKSUMS_SHA256.txt` проверяет опубликованные артефакты до регенерации, но не используется как критерий межплатформенного совпадения повторно экспортированных CAD-бинарников.

## Последствия

- будущие версии больших моделей не раздувают обычную Git-историю;
- документационные изменения не запускают механическую сборку и не расходуют LFS-трафик;
- один полный механический CI-запуск всё равно скачивает весь набор STL/GLB;
- при текущем объёме это около 427 МБ на механический workflow; документационный, Android- и firmware-only diff расходует 0 МБ LFS;
- новый push той же ветки отменяет незавершённый предыдущий workflow через `concurrency`;
- старые бинарные blobs остаются в прежней истории до отдельного согласованного решения;
- межплатформенная воспроизводимость CAD означает совпадение геометрии, семантики и детерминированных исходных текстов, а не обязательный одинаковый SHA производного бинарника, превью или отчёта с таким SHA;
- для полноценной работы с моделями разработчику требуется Git LFS;
- ZIP GitHub может содержать только LFS-указатели, если включение LFS-объектов в архивы не настроено отдельно.

## Проверка

- `node --test tests/buildSystem.test.mjs tests/windowsToolchain.test.mjs`;
- `build.cmd validate` из защищённой рабочей копии;
- `git lfs ls-files` после индексирования миграционного коммита;
- GitHub Actions должен показать один LFS-download только в механической задаче.

## Когда пересматривать

- при приближении к месячному лимиту LFS-трафика или хранилища;
- при переносе генерируемых моделей в Release assets или внешнее хранилище;
- перед любым переписыванием опубликованной Git-истории;
- если PNG начинают занимать сопоставимый объём или отдельные изображения превышают практический порог Git.

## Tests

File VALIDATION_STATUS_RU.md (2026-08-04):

# Статус проверки v0.7.6

## Проверено до передачи update bundle

- синтаксис новых Python- и Node-файлов;
- self-test автоматической упаковки print-layout;
- self-test автоматического размещения ID-выносок;
- self-test идемпотентного применителя;
- структурные fixture-проверки патчей HTML-каталога и генератора механики.

## Результат применения к этому checkout

- После исправления дефектов архива полный защищённый checkout прошёл регенерацию и локальный quality gate: **PASS**.
- После добавления единой сборки и экономного LFS-профиля: 53/53 Node-теста, 101 Markdown-файл, 40/40 STL и 7 current GLB проверены.
- Android application ID и namespace согласованы как `ru.superpommelsandflag.crucian`; APK и обе прошивки собраны в review-ветке.

Обычный запуск применителя пересобирает механические STL/GLB, превью, схемы, слой ID, HTML-каталог и контрольные суммы, затем запускает `quality:gate` и `git diff --check`.

## Исторически подтверждено для опубликованной v0.7.5

- GitHub Actions run [`30761888122`](https://github.com/kva4991/flagpole/actions/runs/30761888122), commit `7e5417b`, успешно собрал Android debug APK и обе PlatformIO-линии;
- эти результаты намеренно не переименовываются в v0.7.6.

## Подтверждено для опубликованной review-ветки v0.7.6

- GitHub Actions run [`30791048730`](https://github.com/kva4991/flagpole/actions/runs/30791048730), commit `dd511f0`;
- Android `assembleDebug` с `versionCode = 5`, `versionName = "0.7.6"`;
- обе PlatformIO-сборки.

Новая миграция Git LFS и единый build-интерфейс пока проверены локально и ожидают отдельного разрешения владельца на commit/push.

## Не проверено аппаратно

- посадка M3/M4 и возможность замены гаек;
- печать на Bambu Lab X1 Carbon;
- реальные размеры плат и разъёмов;
- удержание и радиус изгиба проводов;
- отклик датчиков за мембраной;
- герметичность, конденсация, нагрев и уличная долговечность;
- Android/BLE, PWM, MOSFET и прошивка на реальном устройстве.

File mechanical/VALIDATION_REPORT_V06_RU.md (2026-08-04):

# Проверка STL актуальной механики v0.7.6

- Проверено STL: **40**
- Все замкнуты: **да**
- Направление граней согласовано: **да**
- Каждый файл состоит из одного связного объёма: **да**

Проверка охватывает PETG, TPU 95A, TPU 85A и тестовые купоны.

В этой версии заново проверены половины корпуса, крышка, укороченный световой тоннель, карман AHT20+BMP280, TPU-манжеты, направляющая двух проводов, прокладки и тестовые купоны.

> Замкнутая STL-сетка не доказывает правильность физических посадок, прочность, герметичность или печатаемость без поддержек. Эти свойства проверяются купонами и стендом.

## Файлы

| Файл | Замкнут | Связных объёмов | Грани |
| --- | ---: | ---: | ---: |
| `mechanical/stl_petg_v06/electronics_carrier_open_side_up.stl` | да | 1 | 6964 |
| `mechanical/stl_petg_v06/environment_sensor_pocket_open_side_up.stl` | да | 1 | 8594 |
| `mechanical/stl_petg_v06/photo_tunnel_upright.stl` | да | 1 | 3356 |
| `mechanical/stl_petg_v06/photo_window_retainer_flat.stl` | да | 1 | 840 |
| `mechanical/stl_petg_v06/rotor_half_A_print_flat.stl` | да | 1 | 13116 |
| `mechanical/stl_petg_v06/rotor_half_B_print_flat.stl` | да | 1 | 15300 |
| `mechanical/stl_petg_v06/service_lid_top_face_down.stl` | да | 1 | 4776 |
| `mechanical/stl_petg_v06/stationary_collar_A_print_flat.stl` | да | 1 | 1940 |
| `mechanical/stl_petg_v06/stationary_collar_B_print_flat.stl` | да | 1 | 2068 |
| `mechanical/stl_petg_v06/VEML7700_cradle_flat.stl` | да | 1 | 5524 |
| `mechanical/stl_tpu95_v06/flag_cable_grommet_A_split_face_down.stl` | да | 1 | 860 |
| `mechanical/stl_tpu95_v06/flag_cable_grommet_B_split_face_down.stl` | да | 1 | 860 |
| `mechanical/stl_tpu95_v06/flag_side_wire_guide_closed.stl` | да | 1 | 1684 |
| `mechanical/stl_tpu95_v06/M125_bundle_grommet_A_split_face_down.stl` | да | 1 | 860 |
| `mechanical/stl_tpu95_v06/M125_bundle_grommet_B_split_face_down.stl` | да | 1 | 860 |
| `mechanical/stl_tpu95_v06/M125_pole_sleeve_upright.stl` | да | 1 | 1252 |
| `mechanical/stl_tpu95_v06/pole_collar_liner_A_split_face_down.stl` | да | 1 | 644 |
| `mechanical/stl_tpu95_v06/pole_collar_liner_B_split_face_down.stl` | да | 1 | 644 |
| `mechanical/stl_tpu95_v06/spoke_liner_A_split_face_down.stl` | да | 1 | 860 |
| `mechanical/stl_tpu95_v06/spoke_liner_B_split_face_down.stl` | да | 1 | 860 |
| `mechanical/stl_tpu85_v06/environment_pocket_gasket_flat.stl` | да | 1 | 896 |
| `mechanical/stl_tpu85_v06/lid_gasket_flat.stl` | да | 1 | 896 |
| `mechanical/stl_tpu85_v06/photo_window_gasket_flat.stl` | да | 1 | 840 |
| `mechanical/test_coupons_v06/bearing_seat_32.20_half_A.stl` | да | 1 | 56432 |
| `mechanical/test_coupons_v06/bearing_seat_32.20_half_B.stl` | да | 1 | 56380 |
| `mechanical/test_coupons_v06/bearing_seat_32.35_half_A.stl` | да | 1 | 56600 |
| `mechanical/test_coupons_v06/bearing_seat_32.35_half_B.stl` | да | 1 | 56388 |
| `mechanical/test_coupons_v06/bearing_seat_32.50_half_A.stl` | да | 1 | 56620 |
| `mechanical/test_coupons_v06/bearing_seat_32.50_half_B.stl` | да | 1 | 56560 |
| `mechanical/test_coupons_v06/PETG_drill_skin_0.6_0.8_1.0_coupon.stl` | да | 1 | 45568 |
| `mechanical/test_coupons_v06/PETG_lid_gasket_groove_coupon.stl` | да | 1 | 65852 |
| `mechanical/test_coupons_v06/PETG_M3_captive_nut_trap_coupon.stl` | да | 1 | 42392 |
| `mechanical/test_coupons_v06/PETG_M4_captive_nut_trap_coupon.stl` | да | 1 | 45924 |
| `mechanical/test_coupons_v06/PETG_photo_tunnel_15_18_comparison_coupon.stl` | да | 1 | 81800 |
| `mechanical/test_coupons_v06/PETG_twin_wire_rail_4.2x2.5_coupon.stl` | да | 1 | 51868 |
| `mechanical/test_coupons_v06/PETG_VEML7700_cradle_coupon.stl` | да | 1 | 17952 |
| `mechanical/test_coupons_v06/TPU85_lid_gasket_coupon.stl` | да | 1 | 17520 |
| `mechanical/test_coupons_v06/TPU95_M125_sleeve_OD_15.60.stl` | да | 1 | 40328 |
| `mechanical/test_coupons_v06/TPU95_M125_sleeve_OD_15.80.stl` | да | 1 | 40144 |
| `mechanical/test_coupons_v06/TPU95_M125_sleeve_OD_16.00.stl` | да | 1 | 40480 |

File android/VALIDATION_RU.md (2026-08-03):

# Проверка Android-клиента — v0.7.6

Исходники приложения синхронизированы с версией `0.7.6`: `versionCode = 5`, `versionName = "0.7.6"`, `applicationId = "ru.superpommelsandflag.crucian"`. Kotlin namespace и каталог исходников перенесены согласованно. Функциональный код BLE не менялся.

Сборка v0.7.6 должна быть подтверждена GitHub Actions в review-ветке. Последнее опубликованное доказательство для предыдущего package относится к v0.7.5 и не переносится на новый application ID.

Реальная проверка требует Android-телефон и ESP32-C3: сканирование, bonding, MTU, очередь GATT, смена PIN, команды AUTO/ON/OFF и отключение BLE.

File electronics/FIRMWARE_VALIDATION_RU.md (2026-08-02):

# Проверка прошивки ESP32-C3 — v0.7.4

Код прошивки в механическом обновлении v0.7.4 функционально не изменялся. GitHub Actions run [`30753133808`](https://github.com/kva4991/flagpole/actions/runs/30753133808) для commit `a80263a` успешно собрал и опубликовал артефакты обеих линий:

- `electronics/firmware/esp32_c3_crucian_v06`;
- `electronics/firmware/esp32_c3_flag_light`.

Успешная компиляция не подтверждает PWM, MOSFET, VEML7700, AHT20+BMP280, bonding/PIN или BLE на реальном оборудовании. Нужен электрический стенд с фактическими платами и новой компоновкой бокса.

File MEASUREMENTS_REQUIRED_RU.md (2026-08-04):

# Измерения, без которых нельзя подтвердить окончательные посадки

Использовать штангенциркуль с разрешением 0,05 мм или лучше. Все значения записывать после снятия заусенцев, но до изменения деталей.

Подробное объяснение метода: [`docs/MECHANICAL_FITS_RU.md`](docs/MECHANICAL_FITS_RU.md).

## 1. Вертикальный шток

Принятые рабочие наружный и внутренний диаметры одного сечения и рассчитанная по ним стенка хранятся только в карточке [флагштока #015](catalog/catalog.html#component-015). Небольшую овальность решено отдельно не моделировать. Посадка жёсткой PETG-втулки проверяется серией пробников из заготовки [#401](mechanical/docs/PETG_6806_BEARING_ADAPTER_RU.md). §physicalcomponents1 §bearingadapter1

### Наружный диаметр

Таблица ниже оставлена для необязательной повторной проверки, только если пробная втулка обнаружит заметное изменение посадки по высоте.

| Расстояние от верхнего торца | X, мм | Y, мм |
| --- | ---: | ---: |
| 5 мм |  |  |
| 20 мм |  |  |
| 40 мм |  |  |
| 60 мм |  |  |

Дополнительно:

- длина прямого участка;
- краска;
- наружный шов;
- конусность;
- материал;
- фактический диаметр в зоне четырёх тканевых петель.

### Верхнее отверстие

| Глубина | X, мм | Y, мм |
| --- | ---: | ---: |
| 0 мм |  |  |
| 10 мм |  |  |
| 20 мм |  |  |
| 30 мм |  |  |

Перед окончательной сборкой проверить глубину свободной полости, внутренний шов и фаску. Толщину стенки для текущего проектирования вычислять из двух принятых диаметров, а не поддерживать отдельным измерением.

## 2. Подшипниковый узел

Прежний 6804-2RS несовместим с фактическим древком и не используется. Выбранный кандидат и его стандартные размеры находятся только в карточке [подшипника #008](catalog/catalog.html#component-008). Исходная заготовка жёсткой переходной PETG-втулки и независимых пробников описана в [#401](mechanical/docs/PETG_6806_BEARING_ADAPTER_RU.md); файлы для печати ещё не генерировались.

Если два 6804-2RS уже куплены, записать их фактические размеры только для учёта:

Для каждого из двух подшипников:

| Параметр | Подшипник 1 | Подшипник 2 |
| --- | ---: | ---: |
| наружный диаметр |  |  |
| внутренний диаметр |  |  |
| ширина |  |  |

Не проверять посадку 6804 на шток силой и не использовать молоток.

## 3. Токосъёмник M125

- точная модель;
- диаметр и длина корпуса;
- фланец;
- выступ ротора;
- длина и диаметр пучков проводов;
- роторная и статорная стороны;
- ток каналов;
- момент начала вращения.

### Нижний торец и разгрузка кабеля к аккумулятору

Заготовка [#402](mechanical/docs/LOWER_POLE_CABLE_STRAIN_RELIEF_RU.md) пока
принимает две отдельные жилы Ø2 мм и общий габарит пары 4 мм из карточки
[провода #022](catalog/catalog.html#component-022). Внутренний Ø24,3 мм
подтверждён одинаковым по всей нужной секции. Перед генерацией остаётся определить:

- свободную глубину до элемента стыка секций;
- какая зона внутри трубы занята соединением секций;
- фактический наружный диаметр каждой жилы;
- свободную длину провода между M125, втулкой и аккумулятором.

Сначала проверить шесть рёбер пробниками #40201–#40203 и каналы
#40204–#40206, затем проверить целую втулку 100 циклами изгиба. §lowercablestrain1

## 4. Углепластиковая спица

| Место | X, мм | Y, мм |
| --- | ---: | ---: |
| начало |  |  |
| середина |  |  |
| конец |  |  |

Дополнительно: сплошной пруток или трубка, длина, масса, прямолинейность.

## 5. Крепёж

### Гайки M4

- размер по граням;
- размер по вершинам;
- толщина;
- наличие фасок.

### Гайки M3

- размер по граням;
- размер по вершинам;
- толщина;
- наличие фасок.

После измерения напечатать купон закладной и проверить удержание.

## 6. Электронные платы

| Модуль | Длина | Ширина | Максимальная высота | Примечание |
| --- | ---: | ---: | ---: | --- |
| ESP32-C3 |  |  |  | USB-C и зона антенны |
| DC-DC 12→5 В |  |  |  | дроссель и светодиод |
| LR7843/PC817 |  |  |  | клеммы и затвор |
| VEML7700 |  |  |  | чувствительная зона |
| AHT20+BMP280 |  |  |  | кромка датчиков |

## 7. Кабель и разъём к флагу

- наружный диаметр кабеля;
- число и сечение жил;
- минимальный радиус изгиба;
- длина свободной петли;
- диаметр герметичного коннектора;
- расположение коннектора относительно ткани.

По этим измерениям окончательно задаются ширина и глубина наружной канавки, свободная длина пигтейла и единственный TPU95-ввод около электронного бокса. Параметры генератора пока предварительные; глобально масштабировать модель для подгонки кабеля нельзя.

## 8. Флаг и четыре петли

- фактический размер основы флага;
- наружный диаметр штока в зоне петель;
- толщина сложенной оранжевой ткани;
- длина одной пробной петли после пошива;
- масса флага без неона;
- масса флага с неоном и проводом;
- длина неона по контуру;
- минимальный радиус изгиба неона.

Формула предварительной длины петли:

```text
L = 2 × G + π × Dштока + 6 мм свободного хода + 2 × 15 мм припуска
```

где `G` — расстояние от поверхности вертикального штока до линии пришивания петли на левом крае флага, а `Dштока` берётся из карточки [#015](catalog/catalog.html#component-015). Прежнюю выкройку нельзя считать актуальной. Перед раскроем четырёх петель нужно уточнить `G`, пересчитать длину, сшить и примерить одну петлю.

## 9. Окно VEML7700 и мембрана

### Прозрачное окно

- материал;
- толщина;
- доступный диаметр;
- прозрачность после герметизации;
- фактический размер после вырезания.

### PTFE/ePTFE-мембрана

- габарит;
- клеевой слой;
- толщина;
- рабочая сторона;
- скорость отклика AHT20 за мембраной.

## 10. Bambu Lab X1 Carbon и филамент

- точная марка PETG;
- сушка;
- температура сопла и стола;
- flow ratio;
- pressure advance;
- компенсация отверстий;
- elephant-foot compensation;
- ориентация купона;
- фактический результат тестового куба.

То же отдельно для TPU 95A и TPU 85A.

## 11. Купоны

### Подшипники

Купоны Ø32,20/32,35/32,50 мм относятся только к отклонённому 6804-2RS и не подтверждают посадку нового подшипникового узла.

| Купон | Результат |
| --- | --- |
| 32,20 мм |  |
| 32,35 мм |  |
| 32,50 мм |  |

### Втулка M125 TPU95

| Наружный диаметр | Результат |
| --- | --- |
| 15,60 мм |  |
| 15,80 мм |  |
| 16,00 мм |  |

### Закладная M4

- входит без трещины: да / нет;
- удерживается при переворачивании: да / нет;
- не проворачивается: да / нет;
- выбранная корректировка: ______ мм.

### Утончения под сверление

| Толщина | Результат сверления |
| --- | --- |
| 0,6 мм |  |
| 0,8 мм |  |
| 1,0 мм |  |

### TPU85-прокладки

- крышка;
- окно VEML7700;
- карман AHT20+BMP280;
- мембрана.

Для каждой записать сжатие, восстановление через 24 часа и водяной тест.

## 12. Дополнительные измерения v0.7.3

### Два провода наружной трассы

- наружный диаметр и овальность каждого провода в трёх местах;
- материал и жёсткость изоляции;
- минимальный безопасный радиус изгиба;
- удержание в `#tpu95-10` и вводе `#tpu95-3/#tpu95-4`.

Проверить купон `PETG_twin_wire_rail_4.2x2.5_coupon.stl`: оба провода должны укладываться без сдавливания, не выпадать и не мешать гайке.

### Плата VEML7700

- длина, ширина и толщина платы;
- диаметры и координаты крепёжных отверстий;
- координаты чувствительного элемента;
- высота компонентов и направление выхода проводов.

Проверить купон `PETG_VEML7700_cradle_coupon.stl` до печати полного корпуса.

### Тоннель, климатический карман и мембраны

- диаметр тоннеля и отверстия крышки после печати;
- толщина прозрачного окна и показания VEML7700 до/после установки;
- габариты AHT20+BMP280, положение чувствительной кромки и диаметр жгута;
- размер, активная зона, клеевое кольцо и доступные данные Water Entry Pressure выбранных мембран;
- время отклика влажности и давления до/после мембраны;
- фактическое сжатие прокладок и непрерывность их отпечатка.

## 13. Дополнительные измерения v0.7.4

### Гайки и крепёж

- M4 и M3: размер по граням, толщина, фаска и фактический винт;
- проверить оба купона, удержание, проворот, извлечение и трещины после затяжки;
- записать материал и профиль печати купона.

### Провод и направляющая

- диаметр каждого провода, овальность, жёсткость и минимальный радиус изгиба;
- длина свободного участка до разъёма;
- удержание в дорожке 4,2 × 2,5 мм и в `#tpu95-10` под 35°.

### Мембрана Ø20

- полный диаметр, активный центр, ширина клеевого кольца и толщина;
- проверить, что семь отверстий полностью находятся внутри активной зоны;
- измерить отклик датчиков и водостойкость.

### Электронные платы

Для DC-DC, ESP32-C3, MOSFET, VEML7700 и AHT20+BMP280 измерить габариты, высоту компонентов, отверстия, USB-C, кнопки, клеммы и направление проводов. Только после этого корректировать `#petg-9/#petg-10`.

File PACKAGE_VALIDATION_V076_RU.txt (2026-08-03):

ПРОВЕРКА КУМУЛЯТИВНОГО ПАКЕТА v0.7.6
Дата: 2026-08-02
База: kva4991/flagpole main / 14346190d702c292fded598f55fc431dd92b19ad

ВЫПОЛНЕНО ДО УПАКОВКИ:
- python py_compile: apply_update_v076.py — PASS
- python py_compile: render_catalog_part_callouts_v075.py — PASS
- python py_compile: layout_packing.py — PASS
- layout_packing.py --self-test — PASS
  * стол 256 мм, край 8 мм;
  * минимальный тестовый AABB-зазор 6 мм;
  * backing geometry = false;
  * все тестовые детали стоят на Z=0.
- render_catalog_part_callouts_v075.py --self-test — PASS
  * рамки в границах изображения;
  * рамки не перекрываются;
  * линии короче legacy-позиций;
  * тестовый набор без пересечений.
- apply_update_v076.py --self-test — PASS
  * публичное имя изменено;
  * BLE-имя сохранено;
  * исторические результаты v0.7.5 не переименовываются в v0.7.6;
  * current/validation status формируется отдельно и идемпотентно;
  * повторное применение identity/package изменений идемпотентно.
- patch_catalog_generator на fixture текущих фрагментов — PASS
- patch_model_generator на fixture текущего блока ручных координат — PASS
- синтаксическая компиляция результата model-generator fixture — PASS
- catalog schema v4 и обязательные clean-thumbnail поля — PASS
- полное синтетическое применение `--skip-regeneration` с созданием ZIP — PASS
  * первый запуск: 41 изменённый путь;
  * второй запуск: 0 изменённых путей;
  * хэши всех 61 файлов checkout полностью совпали;
  * полный ZIP и SHA-256 воспроизводимо пересозданы.
- внутренний MANIFEST_SHA256.txt update bundle — сформирован и проверен;
- детерминированный update ZIP распакован в отдельную папку; self-test из распакованного пакета — PASS;
- внешний SHA-256 sidecar update ZIP — проверен.

ЧТО ЗАПУСКАЕТСЯ ПРИ ПРИМЕНЕНИИ К ПОЛНОМУ CHECKOUT:
- npm run identity:generate
- mechanical/generate_models_v06.py
- validate_models_v06.py
- validate_catalog_model_semantics_v075.py
- все текущие генераторы превью/схем
- npm run catalog:generate
- npm run checksums:update
- npm run quality:gate
- git diff --check
- повторный checksums/quality gate и `git diff --check` после обновления status/PROJECT_MANIFEST.json
- создание полного ZIP и SHA-256

НЕ ВЫПОЛНЕНО ВНУТРИ UPDATE BUNDLE ДО ПРИМЕНЕНИЯ:
- полная регенерация реальных 40 STL и 7 GLB;
- сравнение реальных PNG из полного checkout;
- Android/PlatformIO build;
- физическая печать, измерение, дождевой/тепловой тест.

Причина: пакет не дублирует сотни мегабайт неизменённых бинарных файлов. Полная проверка выполняется применителем в локальном checkout и затем повторяется CI после push владельца.

ОБНАРУЖЕНО ПРИ ИНТЕГРАЦИИ В ПОЛНЫЙ CHECKOUT:
- первый запуск в Windows остановился на выводе символа Unicode `→`, потому что применитель не задавал UTF-8 для дочерних Python-процессов; повторная проверка выполняется с `PYTHONUTF8=1` и `PYTHONIOENCODING=utf-8`;
- ADR-0027…0029 не содержали обязательных разделов проекта и были дополнены;
- два существующих теста v0.7.5 не были синхронизированы с v0.7.6 и были исправлены;
- исходный пакет оставлял `ru.quicktickets.crucian`; по требованию владельца application ID, namespace, Kotlin package и путь исходников согласованно изменены на `ru.superpommelsandflag.crucian`.

ИТОГ ЛОКАЛЬНОЙ ИНТЕГРАЦИИ:
- полный quality gate защищённого checkout: PASS;
- Node-тесты: 46/46;
- документация: 100 Markdown-файлов;
- механика: 40/40 STL топологически корректны, 7 current GLB и единственная сервисная крышка подтверждены;
- каталог: 14 подписанных полноразмерных изображений воспроизводятся, миниатюры чистые, пересечения выносок сокращены с 34 до 0;
- Android и обе прошивки ожидают подтверждения GitHub Actions review-ветки;
- физические испытания не выполнялись.

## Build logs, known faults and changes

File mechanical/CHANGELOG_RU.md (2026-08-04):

# Изменения механики

## v0.7.6

- геометрия печатных STL не менялась;
- в интерактивной сцене электроники устранена вторая презентационная копия сервисной крышки;
- добавлены current-only карточки, 2D-выноски и 3D-hotspots; печатные раскладки оставлены без подписей.
- отдельная повторная генерация и нормализованное сравнение подтвердили эквивалентность 40 STL, 7 GLB и 2 JSON-отчётов (49/49); геометрия основного дерева при аудите не перезаписывалась.

## v0.7.4

- полностью параметрические current-детали;
- 40 валидируемых STL и семь current GLB;
- 8×M4 и 10×M3 закладных;
- новая трасса проводов и направляющая около 35°;
- новая база верхней лямки;
- тоннель 15 мм с клеевым резервуаром;
- мембрана Ø20/Ø10 и семь отверстий;
- `#petg-9` и `#petg-10` для электроники;
- новые купоны M3 и 15/18 мм.

История предыдущих версий находится в корневом `CHANGELOG.md` и отчётах обновлений.

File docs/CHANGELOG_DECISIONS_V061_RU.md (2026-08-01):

# Changelog решений v0.6.1

Добавлены новые зафиксированные требования:

## BLE

Изменено решение:

Было:
- возможность сохранять авторизацию между перезапусками.

Стало:
- BLE всегда начинается с окна настройки после подачи питания;
- окно 1 час;
- успешная авторизация держит BLE включённым только до отключения питания.

Причина:
пользователь считает бессмысленным хранить постоянный BLE-режим.

---

## Питание

Добавлено:

- устройство питается от 6 аккумуляторов 18650;
- аккумуляторный блок стабилизирует питание до 12 В.

---

## PIN

Добавлено:

- изменяемый PIN;
- старый PIN обязателен;
- после смены PIN старые bond-записи удаляются.

---

## PWM

Уточнено:

PWM и MOSFET не являются альтернативами.

Правильная схема:

ESP PWM -> MOSFET -> 12V нагрузка.

---

## Android

Добавлено:

Приложение должно:
- называться Crucian;
- использовать BLE;
- выполнять калибровку датчика;
- управлять яркостью;
- менять PIN.

---

## Механика

Добавлено:

Кабель к флагу:
- отдельный выход;
- максимально близко к флагу;
- усиленный участок корпуса.

---

## Материалы

Добавлено:

TPU 95A и TPU 85A используются одновременно:
- 95A — функциональные элементы;
- 85A — уплотнения.

Уточнён основной жёсткий материал:
- ASA предпочтительна для постоянных наружных деталей из-за стойкости к UV и повышенной температуре;
- PETG сохраняется для прототипов, посадочных купонов и защищённых деталей;
- переход с PETG на ASA требует повторной проверки посадок и не подтверждён до печати купонов.

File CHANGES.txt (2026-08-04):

Hardware design modification record for CERN-OHL-S-2.0

Do not remove existing entries. Add the date, author or organisation, and a
brief description whenever modified hardware design source is conveyed.

2026-08-03 — kva4991: The existing Super_pommels_and_flag design through
version 0.7.6 was first released under CERN-OHL-S-2.0. Detailed earlier project
history remains available in CHANGELOG.md and the repository commit history.

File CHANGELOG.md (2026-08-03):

# Changelog

## v0.7.6

- Публичное имя проекта изменено на `Super_pommels_and_flag`; BLE-имя `Crucian` и технические Android/firmware identifiers сохранены для совместимости.
- В карточках чертежей и 3D ID скрыты; полноэкранный viewer получил кнопку с пиктограммой глаза для переключения меток рядом с крестиком.
- Двухмерные ID-выноски автоматически располагаются ближе к целям с проверкой перекрытий и пересечений; создаётся отчёт компоновки.
- PETG/TPU раскладки автоматически уплотняются по реальным AABB с зазорами 6/5 мм и контролем границ стола.
- Уточнено, что канонических жертвенных PETG-подложек под TPU нет: сервисная крышка является функциональной деталью, brim/raft задаётся слайсером.
- Добавлен ограниченный build123d-mcp CAD-процесс с навыками `modeling`, `drawing`, `repair`; остальные найденные наборы не стали обязательными зависимостями.
- Решения закреплены ADR-0027, ADR-0028 и ADR-0029; добавлены проверки UI, миниатюр, компоновки печати и CAD-процесса.

## v0.7.5

- Рабочий HTML-каталог переведён на строгую политику current-only; карточки и GLB v0.5 больше не публикуются рядом с актуальной версией.
- Все непечатные 2D-виды получили воспроизводимые ID-выноски, а непечатные GLB — hotspots с теми же ID.
- Раскладки PETG, TPU 95A и TPU 85A намеренно оставлены без подписей, чтобы не перекрывать ориентацию и зазоры.
- Исправлена интерактивная компоновка электроники: вместо закрытой и поднятой копий теперь присутствует одна поднятая сервисная крышка `#petg-5`.
- Добавлены ADR-0026, политика каталога, проверки неизвестных ID, версии, исключений раскладок и семантического состава GLB.

## v0.7.4

- Текущая механика полностью возвращена в параметрический генератор; переходные сетки v0.7.3 архивированы.
- Добавлены 8×M4 и 10×M3 обслуживаемых закладных, карта крепежа и M3-купон.
- Маршрут проводов доведён до отмеченной точки через `#tpu95-10` под углом около 35° вниз к флагу.
- Верхняя лямка привязана к нижней кромке навершия, нижняя — к низу флага.
- Тоннель VEML7700 сокращён до 15 мм и получил отдельную клеевую полку и купон 15/18 мм.
- Карман датчика адаптирован под мембрану Ø20/Ø10 с семью отверстиями Ø2.
- Добавлены съёмный каркас электроники, опора VEML7700, отдельные чертёж и GLB.
- Рабочий каталог теперь содержит карты крепежа и компоновки вместо внутреннего контактного листа и дублирующего растрового образца рыбы.

## v0.7.3

- Добавлены наружная дорожка двух проводов 4,2 × 2,5 мм, направляющая `#tpu95-10` и два новых печатных купона.
- Реализованы многобарьерная крышка, отдельная vent-мембрана, тоннель VEML7700 Ø11 × 18 мм и съёмный карман AHT20+BMP280.
- Уточнено положение четырёх тканевых петель и сохранена обязательная примерка одной пробной петли.
- Актуальные, исторические и справочные чертежи получили явные статусы; добавлены визуальный аудит и контактный лист.
- Генерация текущей механики проверяет 37 STL и использует переходный набор канонических сеток `source_meshes_v073` для сложных узлов.
- Сохранены полный каталог из 25 карточек, Gradle Wrapper, обе линии PlatformIO и Windows toolchain; регрессии входного архива не перенесены.

## v0.7.2

- Питание флага перенесено под спицу: герметичный 2-pin разъём остаётся снаружи рядом с флагом, провод идёт по открытой наружной канавке и входит в электронный бокс только через `#tpu95-3` / `#tpu95-4`.
- В маршруте добавлена наружная низкая точка перед герметичным вводом и внутренний PETG-мостик разгрузки кабеля.
- Перегенерированы PETG-роторы, TPU95-манжета, сборочные GLB и отдельная интерактивная модель кабельного маршрута.
- Введены стабильные ID деталей `#petg-*`, `#tpu95-*`, `#tpu85-*`; на актуальные раскладки и разнесённый вид нанесены одинаковые ID.
- На сайт добавлена таблица ID и три отдельные очереди печати: PETG, TPU 95A и TPU 85A.
- Белые TPU-детали на статических и интерактивных видах показываются сероватыми для контраста с фоном.
- В карточку светоотражающей ткани добавлены присланные характеристики без выдачи неподтверждённых единиц за измеренные данные.

## v0.7.0

- Добавлены отдельные изменяемые `projectDisplayName` и `bluetoothDeviceName` в `project_identity.json`.
- Добавлена генерация имени в прошивку, Android resources/Kotlin и HTML-каталог.
- Добавлены четыре тканевые петли крепления левого края флага к вертикальному штоку и выкройка 1:1.
- Исправлена формула длины петли: учитывается расстояние от штока до линии пришивания.
- Добавлены параметрические закладные карманы M4/M3 и тестовый купон M4.
- Генератор механики обновлён до v0.6: карман AHT20+BMP280, vent-мембрана, окно VEML7700, PETG/TPU95/TPU85, новые STL и GLB.
- Общий вид v0.5, разнесённый PETG/TPU и раскладка PETG сохранены картинками и добавлены как интерактивные модели.
- В каталоге добавлен fullscreen-режим 3D с кнопкой «На весь экран», крестиком и Escape.
- Из прошивки и Android удалено фиктивное напряжение батареи.
- Android BLE-клиент переработан: явная state machine, последовательная GATT-очередь, тайм-ауты, modern API 33+, cleanup GATT и main-thread callbacks.
- Зафиксировано: текущая чистовая сборка печатается из купленного оранжевого PETG; ASA — возможная будущая перепечатка после повторных купонов.
- Добавлены подробные документы об окончательных посадках, кармане климатического датчика и закладных гайках.

## v0.6.1

- Исправлена RTC-блокировка BLE после Deep-sleep.
- PIN удалён из конфигурационной характеристики.
- Добавлен fail-safe VEML7700 и проверка порядка порогов.
- Добавлены AHT20+BMP280, ADR, Android-каркас, каталог и контролируемая документация.

## v0.5

- Механика под PETG и TPU 95A, невыпадающие вкладыши, STL/GLB и тестовые купоны.

## v0.4 и ранее

- Электрические схемы, ранняя прошивка, шаблон рыбы и перенос спицы между двумя подшипниками.

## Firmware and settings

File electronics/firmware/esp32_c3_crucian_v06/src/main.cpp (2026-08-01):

#include <Arduino.h>
#include <Wire.h>
#include <Preferences.h>
#include <NimBLEDevice.h>
#include <Adafruit_VEML7700.h>
#include <Adafruit_AHTX0.h>
#include <Adafruit_BMP280.h>
#include <esp_sleep.h>
#include <esp_system.h>
#include <cmath>
#include "config.h"

static const NimBLEUUID SERVICE_UUID("d7a10000-4d22-4d86-9287-b5f168000001");
static const NimBLEUUID STATUS_UUID("d7a10000-4d22-4d86-9287-b5f168000002");
static const NimBLEUUID CONTROL_UUID("d7a10000-4d22-4d86-9287-b5f168000003");
static const NimBLEUUID CONFIG_UUID("d7a10000-4d22-4d86-9287-b5f168000004");

enum class WorkMode : uint8_t { Auto = 0, On = 1, Off = 2 };

Preferences prefs;
Adafruit_VEML7700 lightSensor;
Adafruit_AHTX0 ahtSensor;
Adafruit_BMP280 bmpSensor;
NimBLEServer* bleServer = nullptr;
NimBLECharacteristic* statusChr = nullptr;
NimBLECharacteristic* controlChr = nullptr;
NimBLECharacteristic* configChr = nullptr;

RTC_DATA_ATTR bool lampEnabledRtc = false;
RTC_DATA_ATTR uint8_t manualBrightnessRtc = cfg::DEFAULT_MANUAL_BRIGHTNESS;
RTC_DATA_ATTR WorkMode modeRtc = WorkMode::Auto;
RTC_DATA_ATTR uint32_t rtcStateMagic = 0;
RTC_DATA_ATTR bool bleLockedUntilPowerCycleRtc = false;
RTC_DATA_ATTR uint8_t sensorErrorCountRtc = 0;

static constexpr uint32_t RTC_STATE_MAGIC = 0x4352434Eu; // "CRCN"

struct State {
    bool bleWindowActive = true;
    bool bleAuthorized = false;
    bool keepBleUntilPowerLoss = false;
    bool bleForceOff = false;
    bool isConnected = false;
    bool serviceReady = false;
    bool lightSensorReady = false;
    bool sensorFault = false;
    bool aht20Ready = false;
    bool boschReady = false;
    uint8_t sensorErrorCount = 0;
    uint32_t powerOnMs = 0;
    uint32_t storedPin = cfg::FACTORY_SETUP_PIN;
    float dayLux = cfg::DEFAULT_DAY_LUX;
    float nightLux = cfg::DEFAULT_NIGHT_LUX;
    float lastLux = 0.0f;
    float lastTemp = NAN;
    float lastHumidity = NAN;
    float lastPressureHpa = NAN;
    uint8_t currentBrightness = 0;
    String lastCommandResult = "BOOT";
} state;

bool initializeLightSensor() {
    if (!lightSensor.begin()) return false;
    lightSensor.setGain(VEML7700_GAIN_1_8);
    lightSensor.setIntegrationTime(VEML7700_IT_100MS);
    return true;
}

bool readLux(float& value) {
    if (!state.lightSensorReady) {
        state.lightSensorReady = initializeLightSensor();
        if (!state.lightSensorReady) return false;
    }
    const float measured = lightSensor.readLux();
    if (!std::isfinite(measured) || measured < 0.0f) {
        state.lightSensorReady = false;
        return false;
    }
    value = measured;
    return true;
}

bool readI2cRegister(uint8_t address, uint8_t reg, uint8_t& value) {
    Wire.beginTransmission(address);
    Wire.write(reg);
    if (Wire.endTransmission(false) != 0) return false;
    if (Wire.requestFrom(address, static_cast<uint8_t>(1)) != 1) return false;
    value = Wire.read();
    return true;
}

bool initializeBoschSensorAt(uint8_t address) {
    uint8_t chipId = 0;
    if (!readI2cRegister(address, 0xD0, chipId)) return false;
    if (chipId != 0x58) return false; // BMP280
    return bmpSensor.begin(address);
}

bool initializeBoschSensor() {
    return initializeBoschSensorAt(cfg::BOSCH_I2C_ADDRESS_PRIMARY) ||
           initializeBoschSensorAt(cfg::BOSCH_I2C_ADDRESS_SECONDARY);
}

bool initializeAht20() {
    return ahtSensor.begin(&Wire, 0, cfg::AHT20_I2C_ADDRESS);
}

void readEnvironment() {
    if (!state.aht20Ready) state.aht20Ready = initializeAht20();
    sensors_event_t humidityEvent;
    sensors_event_t temperatureEvent;
    if (state.aht20Ready) {
        state.aht20Ready = ahtSensor.getEvent(&humidityEvent, &temperatureEvent);
        if (state.aht20Ready && std::isfinite(temperatureEvent.temperature) &&
            std::isfinite(humidityEvent.relative_humidity)) {
            state.lastTemp = temperatureEvent.temperature;
            state.lastHumidity = constrain(humidityEvent.relative_humidity, 0.0f, 100.0f);
        } else {
            state.aht20Ready = false;
        }
    }

    if (!state.boschReady) state.boschReady = initializeBoschSensor();
    float boschTemperature = NAN;
    float boschPressure = NAN;
    if (state.boschReady) {
        boschTemperature = bmpSensor.readTemperature();
        boschPressure = bmpSensor.readPressure() / 100.0f;
        if (!std::isfinite(boschTemperature) || !std::isfinite(boschPressure)) {
            state.boschReady = false;
        }
    }

    if (!state.aht20Ready && std::isfinite(boschTemperature)) state.lastTemp = boschTemperature;
    if (std::isfinite(boschPressure)) state.lastPressureHpa = boschPressure;
}

uint16_t percentToDuty(uint8_t percent) {
    percent = min<uint8_t>(percent, 100);
    return static_cast<uint16_t>((cfg::PWM_MAX * percent) / 100u);
}

void applyBrightness(uint8_t percent) {
    state.currentBrightness = min<uint8_t>(percent, 100);
    uint16_t duty = percentToDuty(state.currentBrightness);
    if (!cfg::PWM_ACTIVE_HIGH) duty = cfg::PWM_MAX - duty;
    ledcWrite(cfg::PWM_CHANNEL, duty);
    lampEnabledRtc = state.currentBrightness > 0;
}

void fadeTo(uint8_t targetPercent, uint16_t stepDelayMs = 18) {
    targetPercent = min<uint8_t>(targetPercent, 100);
    int current = state.currentBrightness;
    while (current != targetPercent) {
        current += (current < targetPercent) ? 1 : -1;
        applyBrightness(static_cast<uint8_t>(current));
        delay(stepDelayMs);
    }
}

String modeToString(WorkMode mode) {
    switch (mode) {
        case WorkMode::On: return "ON";
        case WorkMode::Off: return "OFF";
        default: return "AUTO";
    }
}

uint8_t computeAutoBrightness(float lux) {
    if (lux >= state.dayLux) return 0;
    if (lux <= state.nightLux) return 100;
    const float span = state.dayLux - state.nightLux;
    if (span < cfg::MIN_CALIBRATION_GAP_LUX) return 100;
    const float x = constrain((state.dayLux - lux) / span, 0.0f, 1.0f);
    return static_cast<uint8_t>(20.0f + x * 80.0f);
}

String printableFloat(float value, uint8_t digits = 1) {
    return std::isfinite(value) ? String(value, static_cast<unsigned int>(digits)) : String("NA");
}

String buildStatusPayload() {
    String payload;
    payload.reserve(180);
    payload += "MODE=" + modeToString(modeRtc);
    payload += ";LUX=" + printableFloat(state.lastLux);
    payload += ";TEMP=" + printableFloat(state.lastTemp);
    payload += ";HUM=" + printableFloat(state.lastHumidity);
    payload += ";PRESS=" + printableFloat(state.lastPressureHpa);
    payload += ";BRI=" + String(state.currentBrightness);
    payload += ";BLE=" + String(state.bleForceOff ? 0 : 1);
    const char* sensorStatus = state.sensorFault ? "FAULT" : (state.sensorErrorCount > 0 ? "RETRY" : "OK");
    payload += ";SENSOR=" + String(sensorStatus);
    const bool environmentReady = state.aht20Ready || state.boschReady;
    const char* environmentStatus = state.aht20Ready && state.boschReady ? "OK" : (environmentReady ? "PARTIAL" : "FAULT");
    payload += ";ENV=" + String(environmentStatus);
    payload += ";BARO=" + String(state.boschReady ? "BMP280" : "NONE");
    payload += ";RESULT=" + state.lastCommandResult;
    return payload;
}

String buildConfigPayload() {
    String payload;
    payload.reserve(150);
    payload += "PROJECT=" + String(cfg::PROJECT_DISPLAY_NAME);
    payload += ";NAME=" + String(cfg::DEVICE_NAME);
    payload += ";DAY=" + String(state.dayLux, 1);
    payload += ";NIGHT=" + String(state.nightLux, 1);
    payload += ";PIN_DEFAULT=" + String(state.storedPin == cfg::FACTORY_SETUP_PIN ? 1 : 0);
    payload += ";WINDOW_MIN=60";
    return payload;
}

void notifyStatus() {
    if (statusChr == nullptr || !state.isConnected) return;
    const String payload = buildStatusPayload();
    statusChr->setValue(payload.c_str());
    statusChr->notify();
}

void saveConfig() {
    prefs.putULong("pin", state.storedPin);
    prefs.putFloat("dayLux", state.dayLux);
    prefs.putFloat("nightLux", state.nightLux);
}

void loadConfig() {
    prefs.begin("crucian", false);
    state.storedPin = prefs.getULong("pin", cfg::FACTORY_SETUP_PIN);
    state.dayLux = prefs.getFloat("dayLux", cfg::DEFAULT_DAY_LUX);
    state.nightLux = prefs.getFloat("nightLux", cfg::DEFAULT_NIGHT_LUX);
    NimBLEDevice::setSecurityPasskey(state.storedPin);
}

void stopBle() {
    bleLockedUntilPowerCycleRtc = true;
    state.bleForceOff = true;
    state.bleWindowActive = false;
    if (NimBLEDevice::isInitialized()) {
        NimBLEDevice::stopAdvertising();
        btStop();
    }
}

void startAdvertising() {
    NimBLEAdvertising* adv = NimBLEDevice::getAdvertising();
    adv->setName(cfg::DEVICE_NAME);
    adv->addServiceUUID(SERVICE_UUID);
    adv->enableScanResponse(true);
    adv->start();
}

class ControlCallbacks : public NimBLECharacteristicCallbacks {
    void onWrite(NimBLECharacteristic* pCharacteristic, NimBLEConnInfo& connInfo) override {
        std::string raw = pCharacteristic->getValue();
        String command(raw.c_str());
        command.trim();
        command.toUpperCase();
        state.lastCommandResult = "ERR_UNKNOWN";

        if (command == "STATUS?") {
            state.lastCommandResult = "OK_STATUS";
            notifyStatus();
            return;
        }
        if (command.startsWith("MODE:")) {
            const String arg = command.substring(5);
            if (arg == "AUTO") {
                modeRtc = WorkMode::Auto;
                state.lastCommandResult = "OK_MODE_AUTO";
            } else if (arg == "ON") {
                modeRtc = WorkMode::On;
                state.lastCommandResult = "OK_MODE_ON";
            } else if (arg == "OFF") {
                modeRtc = WorkMode::Off;
                state.lastCommandResult = "OK_MODE_OFF";
            } else {
                state.lastCommandResult = "ERR_MODE";
            }
        } else if (command.startsWith("BRIGHTNESS:")) {
            const int value = command.substring(11).toInt();
            if (value >= 0 && value <= 100) {
                manualBrightnessRtc = static_cast<uint8_t>(value);
                if (modeRtc == WorkMode::On) fadeTo(manualBrightnessRtc);
                state.lastCommandResult = "OK_BRIGHTNESS";
            } else {
                state.lastCommandResult = "ERR_BRIGHTNESS";
            }
        } else if (command == "BLE:OFF") {
            state.keepBleUntilPowerLoss = false;
            state.lastCommandResult = "OK_BLE_OFF";
            notifyStatus();
            delay(250);
            stopBle();
            return;
        } else if (command == "CALIBRATE:DAY") {
            if (state.sensorFault || state.sensorErrorCount > 0) {
                state.lastCommandResult = "ERR_LIGHT_SENSOR";
            } else if (state.lastLux < state.nightLux + cfg::MIN_CALIBRATION_GAP_LUX) {
                state.lastCommandResult = "ERR_DAY_TOO_LOW";
            } else {
                state.dayLux = state.lastLux;
                saveConfig();
                state.lastCommandResult = "OK_CAL_DAY";
            }
        } else if (command == "CALIBRATE:NIGHT") {
            if (state.sensorFault || state.sensorErrorCount > 0) {
                state.lastCommandResult = "ERR_LIGHT_SENSOR";
            } else if (state.lastLux > state.dayLux - cfg::MIN_CALIBRATION_GAP_LUX) {
                state.lastCommandResult = "ERR_NIGHT_TOO_HIGH";
            } else {
                state.nightLux = state.lastLux;
                saveConfig();
                state.lastCommandResult = "OK_CAL_NIGHT";
            }
        } else if (command.startsWith("PIN:")) {
            const String pair = command.substring(4);
            const int comma = pair.indexOf(',');
            if (comma <= 0) {
                state.lastCommandResult = "ERR_PIN_FORMAT";
            } else {
                const uint32_t oldPin = pair.substring(0, comma).toInt();
                const uint32_t newPin = pair.substring(comma + 1).toInt();
                if (oldPin != state.storedPin) {
                    state.lastCommandResult = "ERR_OLD_PIN";
                } else if (newPin < 100000 || newPin > 999999) {
                    state.lastCommandResult = "ERR_NEW_PIN";
                } else {
                    state.storedPin = newPin;
                    saveConfig();
                    state.lastCommandResult = "OK_PIN_CHANGED";
                    notifyStatus();
                    delay(250);
                    NimBLEDevice::deleteAllBonds();
                    NimBLEDevice::setSecurityPasskey(state.storedPin);
                    bleServer->disconnect(connInfo);
                    return;
                }
            }
        }
        notifyStatus();
    }
};

class ConfigCallbacks : public NimBLECharacteristicCallbacks {
    void onRead(NimBLECharacteristic* pCharacteristic, NimBLEConnInfo&) override {
        const String payload = buildConfigPayload();
        pCharacteristic->setValue(payload.c_str());
    }
};

class ServerCallbacks : public NimBLEServerCallbacks {
    void onConnect(NimBLEServer* pServer, NimBLEConnInfo& connInfo) override {
        state.isConnected = true;
        pServer->updateConnParams(connInfo.getConnHandle(), 24, 48, 0, 180);
    }

    void onDisconnect(NimBLEServer*, NimBLEConnInfo&, int) override {
        state.isConnected = false;
        if (!state.bleForceOff && (state.bleWindowActive || state.keepBleUntilPowerLoss)) {
            NimBLEDevice::startAdvertising();
        }
    }

    uint32_t onPassKeyDisplay() override { return state.storedPin; }

    void onConfirmPassKey(NimBLEConnInfo& connInfo, uint32_t) override {
        NimBLEDevice::injectConfirmPasskey(connInfo, true);
    }

    void onAuthenticationComplete(NimBLEConnInfo& connInfo) override {
        if (!connInfo.isEncrypted() || !connInfo.isBonded()) {
            NimBLEDevice::getServer()->disconnect(connInfo);
            return;
        }
        state.bleAuthorized = true;
        state.keepBleUntilPowerLoss = true;
        state.lastCommandResult = "AUTH_OK";
    }
} serverCallbacks;

void setupBle() {
    NimBLEDevice::init(cfg::DEVICE_NAME);
    NimBLEDevice::setSecurityIOCap(BLE_HS_IO_DISPLAY_ONLY);
    NimBLEDevice::setSecurityAuth(true, true, true);
    NimBLEDevice::setSecurityPasskey(state.storedPin);
    NimBLEDevice::setMTU(185);

    bleServer = NimBLEDevice::createServer();
    bleServer->setCallbacks(&serverCallbacks);
    NimBLEService* service = bleServer->createService(SERVICE_UUID);
    statusChr = service->createCharacteristic(
        STATUS_UUID,
        NIMBLE_PROPERTY::READ | NIMBLE_PROPERTY::NOTIFY | NIMBLE_PROPERTY::READ_ENC,
        200
    );
    controlChr = service->createCharacteristic(
        CONTROL_UUID,
        NIMBLE_PROPERTY::WRITE | NIMBLE_PROPERTY::WRITE_ENC,
        96
    );
    configChr = service->createCharacteristic(
        CONFIG_UUID,
        NIMBLE_PROPERTY::READ | NIMBLE_PROPERTY::READ_ENC,
        160
    );
    controlChr->setCallbacks(new ControlCallbacks());
    configChr->setCallbacks(new ConfigCallbacks());
    service->start();
    bleServer->start();
    startAdvertising();
    state.serviceReady = true;
}

void setup() {
    Serial.begin(115200);
    delay(200);

    const esp_reset_reason_t resetReason = esp_reset_reason();
    if (rtcStateMagic != RTC_STATE_MAGIC || resetReason == ESP_RST_POWERON) {
        rtcStateMagic = RTC_STATE_MAGIC;
        bleLockedUntilPowerCycleRtc = false;
        sensorErrorCountRtc = 0;
    }
    state.bleForceOff = bleLockedUntilPowerCycleRtc;
    state.bleWindowActive = !bleLockedUntilPowerCycleRtc;
    state.sensorErrorCount = sensorErrorCountRtc;
    state.sensorFault = state.sensorErrorCount >= cfg::SENSOR_ERROR_LIMIT;
    state.powerOnMs = millis();

    pinMode(cfg::PIN_PWM, OUTPUT);
    ledcSetup(cfg::PWM_CHANNEL, cfg::PWM_FREQ_HZ, cfg::PWM_RES_BITS);
    ledcAttachPin(cfg::PIN_PWM, cfg::PWM_CHANNEL);
    applyBrightness(0);

    Wire.begin(cfg::PIN_I2C_SDA, cfg::PIN_I2C_SCL);
    state.lightSensorReady = initializeLightSensor();
    state.aht20Ready = initializeAht20();
    state.boschReady = initializeBoschSensor();

    loadConfig();
    if (!bleLockedUntilPowerCycleRtc) {
        setupBle();
    } else {
        Serial.println("BLE remains locked until the next power cycle");
    }
}

void loop() {
    float measuredLux = 0.0f;
    const bool sensorMeasurementValid = readLux(measuredLux);
    if (sensorMeasurementValid) {
        state.lastLux = measuredLux;
        state.sensorErrorCount = 0;
        sensorErrorCountRtc = 0;
        state.sensorFault = false;
    } else {
        if (state.sensorErrorCount < cfg::SENSOR_ERROR_LIMIT) ++state.sensorErrorCount;
        sensorErrorCountRtc = state.sensorErrorCount;
        state.sensorFault = state.sensorErrorCount >= cfg::SENSOR_ERROR_LIMIT;
        Serial.printf("VEML7700 read error %u/%u\n", state.sensorErrorCount, cfg::SENSOR_ERROR_LIMIT);
    }

    readEnvironment();

    if (state.sensorFault) {
        if (state.currentBrightness != 0) fadeTo(0);
    } else if (!sensorMeasurementValid) {
        // До порога отказа не меняем нагрузку по устаревшему значению.
    } else if (modeRtc == WorkMode::Off) {
        if (state.currentBrightness != 0) fadeTo(0);
    } else if (modeRtc == WorkMode::On) {
        if (state.currentBrightness != manualBrightnessRtc) fadeTo(manualBrightnessRtc);
    } else {
        const uint8_t target = computeAutoBrightness(state.lastLux);
        if (target != state.currentBrightness) fadeTo(target, 10);
    }

    if (state.serviceReady && !state.bleForceOff) notifyStatus();

    const bool bleSessionAllowed = state.keepBleUntilPowerLoss ||
        (millis() - state.powerOnMs) < cfg::BLE_IDLE_WINDOW_MS;
    state.bleWindowActive = bleSessionAllowed;
    if (!bleSessionAllowed && !state.isConnected && !state.keepBleUntilPowerLoss && !state.bleForceOff) {
        stopBle();
    }

    if (state.currentBrightness == 0 && state.bleForceOff) {
        Serial.println("Entering deep sleep for day mode");
        delay(100);
        esp_sleep_enable_timer_wakeup(static_cast<uint64_t>(cfg::DAY_SLEEP_SEC) * 1000000ULL);
        esp_deep_sleep_start();
    }

    delay(state.currentBrightness > 0 ? cfg::NIGHT_RECHECK_MS : cfg::DAY_RECHECK_MS);
}

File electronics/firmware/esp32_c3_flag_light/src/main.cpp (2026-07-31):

#include <Arduino.h>
#include <Wire.h>
#include <Adafruit_VEML7700.h>

#include <algorithm>
#include <array>
#include <cmath>

#include "driver/gpio.h"
#include "esp_sleep.h"

#include "config.h"

using namespace FlagLightConfig;

namespace {

Adafruit_VEML7700 lightSensor;

// Values stored in RTC memory survive Deep-sleep, but are reset on power loss.
RTC_DATA_ATTR bool rtcLampOn = false;
RTC_DATA_ATTR uint8_t rtcDarkCount = 0;
RTC_DATA_ATTR uint8_t rtcLightCount = 0;
RTC_DATA_ATTR uint8_t rtcSensorFailureCount = 0;
RTC_DATA_ATTR uint32_t rtcCycleNumber = 0;

constexpr gpio_num_t LAMP_GPIO = static_cast<gpio_num_t>(PIN_LAMP_CONTROL);

int lampLevel(const bool on) {
    const bool high = LAMP_ACTIVE_HIGH ? on : !on;
    return high ? HIGH : LOW;
}

void logLine(const char *message) {
    if constexpr (ENABLE_SERIAL_LOG) {
        Serial.println(message);
    }
}

void restoreLampOutputAfterWake() {
    // The output may still be held from the previous Deep-sleep cycle.
    // Configure the internal output state first, then release the pad hold;
    // this avoids a short pulse on the lamp control line.
    pinMode(PIN_LAMP_CONTROL, OUTPUT);
    digitalWrite(PIN_LAMP_CONTROL, lampLevel(rtcLampOn));
    gpio_hold_dis(LAMP_GPIO);
    digitalWrite(PIN_LAMP_CONTROL, lampLevel(rtcLampOn));
}

void setLamp(const bool on) {
    rtcLampOn = on;
    gpio_hold_dis(LAMP_GPIO);
    pinMode(PIN_LAMP_CONTROL, OUTPUT);
    digitalWrite(PIN_LAMP_CONTROL, lampLevel(on));
}

void holdLampOutputForDeepSleep() {
    pinMode(PIN_LAMP_CONTROL, OUTPUT);
    digitalWrite(PIN_LAMP_CONTROL, lampLevel(rtcLampOn));
    gpio_hold_en(LAMP_GPIO);
    gpio_deep_sleep_hold_en();
}

bool readMedianLux(float &luxOut) {
    Wire.begin(PIN_I2C_SDA, PIN_I2C_SCL);
    Wire.setClock(100000);

    if (!lightSensor.begin(&Wire)) {
        return false;
    }

    lightSensor.enable(true);

    std::array<float, LUX_SAMPLE_COUNT> values{};
    uint8_t validCount = 0;

    for (uint8_t i = 0; i < LUX_SAMPLE_COUNT; ++i) {
        const float lux = lightSensor.readLux(VEML_LUX_AUTO);
        if (std::isfinite(lux) && lux >= 0.0F) {
            values[validCount++] = lux;
        }
        delay(SAMPLE_PAUSE_MS);
    }

    // Put the VEML7700 into shutdown before the ESP enters Deep-sleep.
    lightSensor.enable(false);

    if (validCount < 3) {
        return false;
    }

    std::sort(values.begin(), values.begin() + validCount);
    luxOut = values[validCount / 2];
    return true;
}

void applyLuxDecision(const float lux) {
    if (!rtcLampOn) {
        rtcLightCount = 0;

        if (lux <= LUX_TURN_ON) {
            if (rtcDarkCount < UINT8_MAX) {
                ++rtcDarkCount;
            }
        } else {
            rtcDarkCount = 0;
        }

        if (rtcDarkCount >= DARK_CONFIRMATIONS) {
            setLamp(true);
            rtcDarkCount = 0;
        }
        return;
    }

    rtcDarkCount = 0;

    if (lux >= LUX_TURN_OFF) {
        if (rtcLightCount < UINT8_MAX) {
            ++rtcLightCount;
        }
    } else {
        rtcLightCount = 0;
    }

    if (rtcLightCount >= LIGHT_CONFIRMATIONS) {
        setLamp(false);
        rtcLightCount = 0;
    }
}

void handleSensorFailure() {
    if (rtcSensorFailureCount < UINT8_MAX) {
        ++rtcSensorFailureCount;
    }

    // Preserve the previous state through brief I2C errors. After repeated
    // failures, turn the lamp off so a broken or flooded sensor cannot leave
    // the light permanently on during daytime.
    if (rtcSensorFailureCount >= SENSOR_FAILURE_LIMIT) {
        rtcDarkCount = 0;
        rtcLightCount = 0;
        setLamp(false);
    }
}

void runMeasurementCycle() {
    ++rtcCycleNumber;

    float lux = 0.0F;
    const bool sensorOk = readMedianLux(lux);

    if (sensorOk) {
        rtcSensorFailureCount = 0;
        applyLuxDecision(lux);

        if constexpr (ENABLE_SERIAL_LOG) {
            Serial.printf(
                "cycle=%lu lux=%.3f lamp=%s dark=%u light=%u failures=%u\n",
                static_cast<unsigned long>(rtcCycleNumber),
                lux,
                rtcLampOn ? "ON" : "OFF",
                rtcDarkCount,
                rtcLightCount,
                rtcSensorFailureCount
            );
        }
    } else {
        handleSensorFailure();
        if constexpr (ENABLE_SERIAL_LOG) {
            Serial.printf(
                "cycle=%lu sensor=ERROR lamp=%s failures=%u\n",
                static_cast<unsigned long>(rtcCycleNumber),
                rtcLampOn ? "ON" : "OFF",
                rtcSensorFailureCount
            );
        }
    }
}

[[noreturn]] void enterDeepSleep() {
    holdLampOutputForDeepSleep();
    esp_sleep_enable_timer_wakeup(
        static_cast<uint64_t>(SLEEP_SECONDS) * 1000000ULL
    );

    if constexpr (ENABLE_SERIAL_LOG) {
        Serial.flush();
    }

    esp_deep_sleep_start();
    while (true) {
        delay(1000);
    }
}

} // namespace

void setup() {
    if constexpr (ENABLE_SERIAL_LOG) {
        Serial.begin(115200);
        delay(200);
    }

    // A cold power-up starts safely with the lamp off. Deep-sleep wakeups keep
    // the values stored in RTC memory.
    const esp_sleep_wakeup_cause_t wakeCause = esp_sleep_get_wakeup_cause();
    if (wakeCause == ESP_SLEEP_WAKEUP_UNDEFINED) {
        rtcLampOn = false;
        rtcDarkCount = 0;
        rtcLightCount = 0;
        rtcSensorFailureCount = 0;
        rtcCycleNumber = 0;
    }

    restoreLampOutputAfterWake();

    if constexpr (CONTINUOUS_TEST_MODE) {
        logLine("Continuous test mode: Deep-sleep is disabled");
        return;
    }

    runMeasurementCycle();
    enterDeepSleep();
}

void loop() {
    if constexpr (CONTINUOUS_TEST_MODE) {
        runMeasurementCycle();
        delay(CONTINUOUS_TEST_INTERVAL_MS);
    }
}

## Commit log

2026-07-31 Initial public prototype v0.5: PETG/TPU mechanics, electronics and firmware
    [M125_bundle_grommet_A_split_face_down.stl, M125_bundle_grommet_B_split_face_down.stl, TPU_lid_gasket_coupon.stl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]
2026-08-01 Fix Crucian CI build contracts
    [main.cpp]
2026-08-01 Document selected KBXlife battery case
2026-08-01 Document selected ESP32-C3 Mini Plus board
2026-08-01 Document selected eletechsup 5V buck converter
2026-08-01 Document selected TZT LR7843 MOSFET module
2026-08-01 Document selected VEML7700 light sensor
2026-08-01 Add selected ground flagpole to catalog
2026-08-01 Document selected ELEGOO TPU 95A filament
2026-08-01 Document selected ERYONE TPU 85A filament
2026-08-01 Document selected 2-pin waterproof connectors
2026-08-01 Document selected RXEF075 PPTC fuses
2026-08-01 Require sealed 2RS bearing candidate
2026-08-01 Prefer ASA for permanent outdoor printed parts
2026-08-01 feat: replace NTC with digital environment sensors
    [main.cpp]
2026-08-01 feat: select combined AHT20 BMP280 sensor
2026-08-01 docs: define protected environment sensor pocket
2026-08-01 docs(catalog): add vent membrane hardware and wiring
2026-08-01 docs(catalog): add cut light well window
2026-08-01 docs(catalog): specify outdoor sewing thread
2026-08-01 Release cumulative v0.7.0 handoff
    [M125_bundle_grommet_A_split_face_down.stl, M125_bundle_grommet_B_split_face_down.stl, M125_pole_sleeve_upright.stl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]
2026-08-01 Fix ESP32 telemetry formatting build
    [main.cpp]
2026-08-01 Release v0.7.2 cable route and part IDs
    [flag_cable_grommet_A_split_face_down.stl, flag_cable_grommet_B_split_face_down.stl]
2026-08-02 Release v0.7.3 weatherproofing and drawing audit
    [PETG_VEML7700_cradle_coupon.stl, PETG_environment_sensor_pocket_assembly.stl, PETG_photo_tunnel_assembly.stl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]
2026-08-02 Release v0.7.4 fully parametric mechanics
    [PETG_M3_captive_nut_trap_coupon.stl, PETG_VEML7700_cradle_coupon.stl, PETG_environment_sensor_pocket_assembly.stl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]
2026-08-02 Release v0.7.5 current-only catalog and callouts
2026-08-04 Prepare v0.7.6 canonical CAD and prune legacy artifacts
    [M125_bundle_grommet_A_split_face_down.stl, M125_bundle_grommet_B_split_face_down.stl, M125_pole_sleeve_upright.stl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]
2026-08-04 Use CI Python for canonical CAD build
2026-08-04 Install canonical CAD dependencies in CI
2026-08-04 Validate CAD reproducibility semantically across platforms
